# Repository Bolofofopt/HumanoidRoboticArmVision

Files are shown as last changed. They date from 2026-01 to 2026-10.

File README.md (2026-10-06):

<div align="center">

# 🤖 Vision-Controlled Robotic Arm

**A 3D-printed robotic arm that mimics your movements in real time using just a camera.**

<video src="media/demo.mp4" controls controlsList="nodownload"></video>







</div>

---

> **🌐 Language Note:** This README is written in **English**. However, the full technical report ([PDF](RIA_G7_Relatorio_Final_Braco_Robotico.pdf)) is in **Portuguese**. All source code files have two versions: an English version and a Portuguese version (files ending in `_PT`). Both versions are functionally identical; only comments and variable names differ. Use whichever you prefer.

---

## 📖 What Is This Project?

This is a **humanoid robotic arm** that imitates your arm and hand movements in real time. Instead of buttons or joysticks, you simply stand in front of a camera: the system recognizes your gestures and the robot copies them automatically.

The arm has **7 independent degrees of freedom**: 5 fingers that open and close, an elbow that goes up and down, and a rotating base that turns left and right. The entire mechanical structure was 3D-printed using the open-source [InMoov](https://inmoov.fr/) project as a foundation.

**This README is a complete tutorial.** If you follow every step, you'll be able to build your own robotic arm, even without much experience in programming or electronics.

---

## 🎬 Demo

https://github.com/user-attachments/assets/58556680-eb30-46fe-b466-be9ada0d2111

---

## 📁 Repository Structure

Before starting, it's useful to know where everything is:

```
HumanoidRoboticArmVision/
│
├── 📄 README.md                          ← You are here! The full tutorial
├── 📄 REQUIREMENTS.txt                   ← Software versions and libraries
├── 📄 LICENSE                            ← MIT License
├── 📄 RIA_G7_Relatorio_Final_Braco_Robotico.pdf  ← Full technical report (Portuguese)
│
├── 📂 code/
│   ├── 📂 Arduino/Final_Ard/
│   │   ├── 📂 MotorDriver/               ← Arduino MEGA firmware (English)
│   │   ├── 📂 MotorDriver_PT/            ← Arduino MEGA firmware (Portuguese)
│   │   └── 📂 Arduino_Uno_CNC_Final/     ← Arduino Uno firmware (stepper motor)
│   │
│   ├── 📂 RPi/Final_RPI/
│   │   ├── ArmController.py              ← Computer vision for Raspberry Pi (English)
│   │   └── ArmController_PT.py           ← Computer vision for Raspberry Pi (Portuguese)
│   │
│   └── 📂 PC/
│       ├── VisionDebugger_PC.py           ← Debug tool for PC (English)
│       ├── VisionDebugger_PC_PT.py        ← Debug tool for PC (Portuguese)
│       ├── hand_landmarker.task           ← MediaPipe model (hand)
│       └── pose_landmarker_lite.task      ← MediaPipe model (body)
│
├── 📂 Codigos_PDFs/                       ← Source code as PDF (report annexes, Portuguese)
│
└── 📂 media/                              ← Project images and GIFs
```

> **Note:** Each code file exists in **two versions**: English and Portuguese (`_PT` suffix). They are functionally identical; only the comments and variable names change.

---

## 🧾 Bill of Materials

Here's everything you need to build the arm. Some components can be swapped for equivalents.

### Electronics & Computing

| Component | Reference | Qty | Notes |
| :--- | :--- | :-: | :--- |
| Raspberry Pi | **Raspberry Pi 5** (8GB) |  1  | The "brain", processing real-time AI vision |
| Camera | **Raspberry Pi Camera Module 3** |  1  | Dedicated CSI camera for the RPi |
| Camera Cable (RPi 5) | **22-pin to 15-pin FPC cable** |  1  | Required adapter cable for RPi 5 mini-CSI port |
| MicroSD Card | **32 GB or 64 GB** (Class 10/A2) |  1  | OS (Bookworm) & software drive for Raspberry Pi 5 |
| Active Cooler | **Official RPi 5 Active Cooler** |  1  | Recommended heatsink + fan to avoid thermal throttle  |
| Arduino | **Arduino MEGA 2560** |  1  | Central motor controller |
| Arduino | **Arduino Uno R3** |  1  | Dedicated to the base stepper motor |
| Servo Driver | **PCA9685** (16-channel, I2C) |  1  | Controls all servos using just 2 pins |
| Stepper Driver | **A4988** |  1  | Plugs into the CNC Shield (with mini heatsink) |
| CNC Shield | **CNC Shield V3** |  1  | Mounts directly on the Arduino Uno |

### Motors & Actuators

| Component | Reference | Qty | Notes |
| :--- | :--- | :-: | :--- |
| Servo Motor (elbow) | **DS5160** (60 kgf·cm) |  1  | Needs to be powerful to support the forearm's weight  |
| Servo Motor (fingers + wrist) | **MG996R** (9-11 kgf·cm) |  6  | 5 for fingers + 1 for wrist rotation |
| Stepper Motor (base) | **17HS4401S** (NEMA 17) |  1  | Precise rotation of the base (Yaw axis) |

### Structure & Mechanics

| Component | Specification | Qty | Notes |
| :--- | :--- | :-----: | :--- |
| PLA Filament | 1.75mm, 1 kg spool |  ~1 kg  | For 3D printing all parts (hand, forearm, custom base, etc.) |
| Springs | 3/16″ x 1-3/4″ (4.8mm x 44.5mm) | 5 | Finger return mechanism |
| Tendons | Braided fishing line, 0.8mm, 200LB | 5x 50cm | Pull the fingers closed (~2.5m total) |
| Teflon Tubes | ID 1.5mm x OD 2.5mm | ~160cm  | Guide the tendons through forearm and fingers |
| Bearing | Commercial ball bearing | 1 | Connects fixed base to rotating upper base |
| Magnets | Neodymium Ø 2.5mm, height 1mm | 5 | Magnetic fingertip attachments |

### Power & Connectivity

| Component | Specification | Notes |
| :--- | :--- | :--- |
| Power Supply 1 | **7V / 3A DC** | For the servo motors (via PCA9685 V+ screw terminal) |
| Power Supply 2 | **12-13V / 2A DC** | For the stepper motor (via CNC Shield power screw) |
| RPi 5 Power | **Official 27W USB-C (5V/5A)** | Powers the Raspberry Pi 5 (and USB-connected boards) |
| USB Cables | **USB-A to USB-B** (2 units) | Connects both Arduinos to PC/RPi |
| DC Jack Adapters | **5.5×2.1mm to screw terminal**| 2 units to wire DC supplies into screw terminals |
| Dupont Jumper Wires | **M-F & M-M ribbon set (40p)** | UART serial (RPi ↔ MEGA ↔ Uno) and I2C connections |

### Consumables & Fasteners

| Component | Notes |
| :--- | :--- |
| Assorted screws (M3, M4) | M3 (8–30mm) & M4 screws, nuts, and washers for assembly |
| Heat shrink tubing | To insulate soldered wire joints |
| Hookup wire (Cabo unifilar) | Power distribution and common ground connections |
| Polyimide tape (Kapton) | Heat protection and wire bundling |
| Soldering flux & solder wire  | RMA flux and solder for secure electrical connections |
| Ecoflex™ 00-10 (RTV Silicone) | Optional: molded grip pads on fingertips |

---

## 💰 Estimated Project Cost

Below is an estimated cost breakdown for the entire project, based on **European market prices (October 2026)**. Prices are in **EUR (€)** and reflect typical online retail prices including VAT.

> **💡 Clones vs. Official:** Components marked with ★ have widely used compatible/clone alternatives (e.g., AliExpress, Amazon). Choosing clones for the microcontrollers and drivers can save **€50–€80** without sacrificing functionality.

### 1. Computing & Control Electronics

| Component | Ref. / Spec | Qty |  Unit Price  | Subtotal | Notes |
| :--- | :--- | :-: | :---: | :---: | :--- |
| Raspberry Pi | RPi 5 (8 GB) |  1  |  ~€85.00 ¹ | ~€85.00 | ¹ Official MSRP; street retail €90–€105 |
| Camera Module | RPi Camera Module 3 |  1  | ~€28.00 | ~€28.00 | Standard CSI camera (12 MP, autofocus) |
| Camera Adapter Cable | 22-pin mini to 15-pin FPC (RPi 5) |  1  | ~€3.50 | ~€3.50 | Required: RPi 5 uses mini CSI connector |
| MicroSD Card | 32 GB or 64 GB (Class 10 / A2) |  1  | ~€8.00 | ~€8.00 | For Raspberry Pi OS (Bookworm) & software  |
| Active Cooler | Official RPi 5 Active Cooler |  1  | ~€6.00 | ~€6.00 | Prevents thermal throttling during vision  |
| Arduino ★ | Arduino MEGA 2560 |  1  |  ~€20.00 ² | ~€20.00 | ² Quality clone; official Arduino is ~€45  |
| Arduino ★ | Arduino Uno R3 |  1  |  ~€12.00 ² | ~€12.00 | ² Quality clone; official Arduino is ~€28  |
| Servo Driver | PCA9685 (16-ch, I2C) |  1  | ~€5.00 | ~€5.00 | ★ Clones available from ~€3.50 |
| Stepper Driver | A4988 |  1  | ~€4.00 | ~€4.00 | Includes mini aluminum heatsink |
| CNC Shield | CNC Shield V3 |  1  | ~€5.00 | ~€5.00 | Plugs directly onto Arduino Uno |
| **Computing Subtotal**  | | | | **~€176.50** | |

### 2. Motors & Actuators

| Component | Ref. / Spec | Qty |  Unit Price  | Subtotal | Notes |
| :--- | :--- | :-: | :---: | :---: | :--- |
| Servo Motor (elbow) | DS5160 (60 kgf·cm) |  1  | ~€35.00 | ~€35.00 | High-torque digital metal-gear servo |
| Servo Motor (fingers + wrist) | MG996R (metal gear) |  6  |  ~€8.90 ³ | ~€53.40 | ³ Retail unit price; 6-pack clones ~€28  |
| Stepper Motor (base) | 17HS4401S (NEMA 17) |  1  | ~€12.00 | ~€12.00 | Standard bipolar stepper for base yaw |
| **Motors Subtotal** | | | | **~€100.40** | **~€75.00** with clone 6-pack |

### 3. Power & Connectivity

| Component | Specification | Qty |  Unit Price  | Subtotal | Notes |
| :--- | :--- | :-: | :---: | :---: | :--- |
| Power Supply 1 | 7 V / 3 A DC |  1  | ~€15.00 | ~€15.00 | Powers servos via PCA9685 V+ terminal |
| Power Supply 2 | 12 V / 2 A DC |  1  | ~€12.00 | ~€12.00 | Powers stepper via CNC Shield |
| RPi 5 Power Supply | Official 27 W USB-C (5V/5A) |  1  | ~€14.00 | ~€14.00 | Recommended official supply |
| USB Cables | USB-A to USB-B (for Arduinos)  |  2  | ~€4.00 | ~€8.00 | Connects Uno & MEGA |
| DC Jack Adapters | 5.5×2.1mm female to screw ter. |  2  | ~€1.00 | ~€2.00 | Wire barrel PSUs into screw terminals |
| Dupont Jumper Wires | 40-pin ribbon (M-M & M-F) |  1  | ~€3.50 | ~€3.50 | For UART & I2C communication wires |
| **Power Subtotal** | | | |  **~€54.50** | |

### 4. Structure, Hardware & Mechanics

| Component | Specification | Qty |  Unit Price  | Subtotal | Notes |
| :--- | :--- | :-: | :---: | :---: | :--- |
| PLA Filament | 1.75 mm, 1 kg spool |  1  | ~€20.00 | ~€20.00 | ~1 kg used for arm, base, and brim/test |
| Extension Springs | 3/16″ × 1-3/4″ (4.8mm × 44.5mm) |  5  | N/A | ~€7.50 ⁴  | ⁴ What we paid: €7.49 |
| Tendons (Fishing Line) | Braided 200 LB, 0.8 mm (100m spool) |  1  | N/A | ~€8.00 ⁴  | ⁴ What we paid: €8.12 |
| Teflon Tubes (PTFE) | ID 1.5 mm × OD 2.5 mm (~1.6m) |  1  | N/A | ~€2.00 ⁴  | ⁴ What we paid: €2.00 |
| Bearing | Deep groove ball bearing (base joint) |  1  | ~€3.00 | ~€3.00 | Commercial hardware for rotating base |
| Neodymium Magnets | Ø 2.5 mm × 1 mm |  5  | N/A | ~€4.60 ⁴  | ⁴ What we paid: €4.60 |
| Screws & Fasteners Kit | Assorted M3 / M4 (screws, nuts, etc.) |  1  | ~€10.00 | ~€10.00 | Hex socket screws, nuts, and washers |
| **Structure Subtotal** | | | |  **~€55.10** | |

### 5. Consumables & Assembly Supplies

| Component | Specification / Ref. |  Subtotal  | Notes |
| :--- | :--- | :---: | :--- |
| Heat shrink tubing | Assorted diameters | ~€3.50 ⁴ | ⁴ What we paid: €3.51 |
| Polyimide tape (Kapton) | Ref. 095-0793 | ~€5.00 ⁴ | ⁴ What we paid: €5.03 |
| Hookup wire (Cabo unifilar) | Single core copper wire  | ~€4.50 ⁴ | ⁴ What we paid: €4.49 |
| Soldering Flux & Solder | RMA Flux (Ref. 096-0207) | ~€5.00 ⁴ | ⁴ Flux €1.99 + solder wire for wire splices |
| Ecoflex™ 00-10 *(optional)* | RTV Silicone trial kit |  ~€35.00 ⁴ | ⁴ What we paid: €35.00 (fingertip pads) |
| **Consumables Subtotal** | | **~€18.00**| **~€53.00** including Ecoflex™ 00-10 |

### 📊 Total Estimated Cost Comparison

| Scenario | Estimated Total |
| :--- | :---: |
| 🟢 **Budget Build** (AliExpress clones, servo multipack, no Ecoflex) | **~€330 – €370** |
| 🟡 **Mid-range Build** (mix of official/quality clones, without Ecoflex) | **~€400 – €440** |
| 🟡 **Mid-range Build** (with Ecoflex silicone grip pads) | **~€435 – €475** |
| 🔴 **Full Official Build** (official Arduinos, retail prices, all accessories + Ecoflex) | **~€510 – €570** |

> **🎓 What We Actually Spent (Our Real Out-of-Pocket Cost):**
> When we built this arm at our university, we didn't have to buy everything from scratch. As you can see in our project report ([`RIA_G7_Relatorio_Final_Braco_Robotico.pdf`](RIA_G7_Relatorio_Final_Braco_Robotico.pdf), Section 5.5, Table 4), our lab already had key high-value components in stock (*"emStock"*): the **Raspberry Pi 5**, **Camera Module 3**, **Arduino MEGA**, **Arduino Uno**, **CNC Shield V3**, **DS5160 Servo**, and **NEMA 17 Stepper**.
>
> Because of that, our **actual out-of-pocket spending was only ~€73 to €118** (mainly for the springs, teflon tubes, fishing line, magnets, heat shrink, Kapton tape, wires, flux, and silicone). If you're building this in a university or makerspace with shared equipment, your upfront cost will likely be similarly low!

> **📝 Notes from Our Experience:**
> - **Raspberry Pi 5 Availability:** It's the most expensive component in the build. We recommend buying from official approved resellers (like Kubii, BerryBase, or Pimoroni) near MSRP (~€85–€90), as general marketplaces like Amazon often mark it up to €95–€110 depending on stock.
> - **3D Printing:** We printed all our parts on our Bambu Lab A1. If you don't have access to a 3D printer and need to outsource the printing, expect an additional commercial printing fee of €40–€90.
> - **Bulk Consumables:** We had to buy items like fishing line (100m spool), PTFE tubing, screws, and magnets in packs much larger than what our arm actually needed, so you'll end up with plenty of leftover materials for future maker projects, just like we did.

---

## 🔧 Step 1: 3D Printing the Parts

The arm's structure is based on the open-source **InMoov** project. You need to download the STL files and print them.

### Where to Download the Models

| Part | Link |
| :--- | :--- |
| 🖐️ Hand and Forearm  | [InMoov: Hand and Forearm](https://inmoov.fr/hand-and-forarm) |
| 🖐️ Hand (I2 version) | [InMoov: Hand I2](https://inmoov.fr/hand-i2) |
| 🏗️ Custom Base | [Custom Base STL Files](Custom_Base_STL/) |

> **💡 Note:** The base parts are not from InMoov. They were exclusively created by us for this project. You can find the STL files in the `Custom_Base_STL` folder in this repository.

> **💡 Tip:** The **Hand I2** version is the most recent and includes design improvements for the fingers. We recommend using this one.

### Print Settings

We used a **Bambu Lab A1** printer, but any FDM printer will work with these settings:

| Parameter |  InMoov Parts | Custom Parts (Base) |
| :--- | :---: | :---: |
| **Material** | PLA | PLA |
| **Nozzle Temperature** | 220°C | 220°C |
| **Bed Temperature** | 65°C | 65°C |
| **Layer Height** | 0.20mm | 0.20mm |
| **Infill Density** | **30%** | **25%** |
| **Wall Loops** | 2 | 2 |
| **Speed** | Standard (100%) | Standard (100%) |

### ⚠️ Common Issue: Warping

During printing, part edges may lift off the bed (called _warping_). If this happens:

1. **Enable "Brim"** in your slicer: this creates a thin rim around the part that increases bed adhesion.
2. **You don't need** to raise the bed temperature or lower the speed. With Brim enabled, standard settings work just fine.

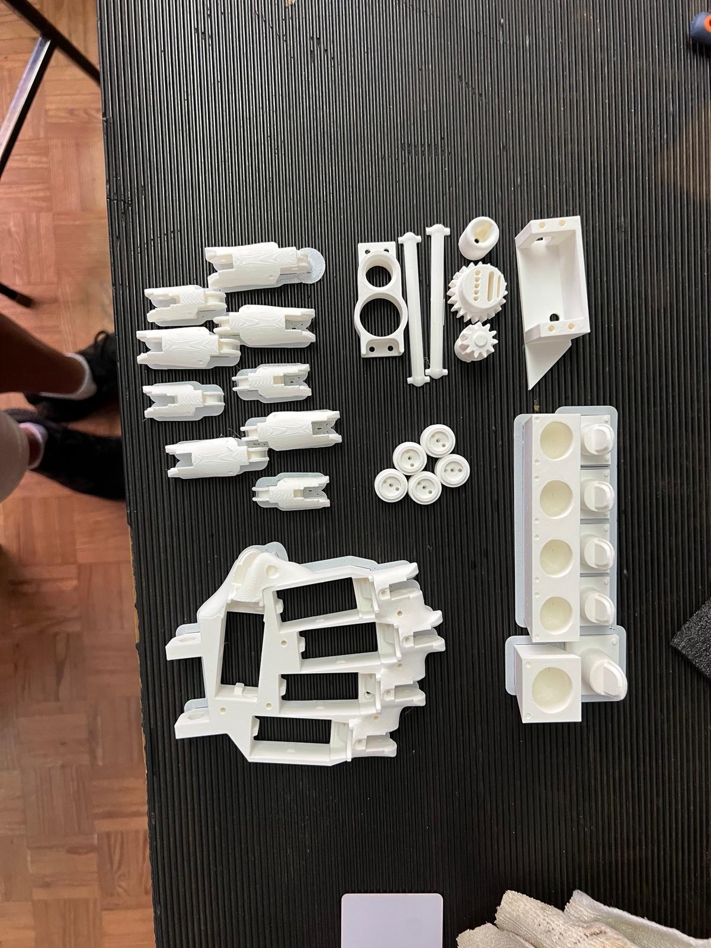
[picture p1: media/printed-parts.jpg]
3D printed parts


---

## 🔩 Step 2: Mechanical Assembly

After printing all the parts, it's time to assemble.

### Hand and Forearm Assembly

Follow the official InMoov instructions:

- 📘 [Assembly guide: Hand and Forearm](https://inmoov.fr/hand-and-forarm)
- 📘 [Assembly guide: Hand I2](https://inmoov.fr/hand-i2)

Each InMoov page has step-by-step photos and videos explaining how to thread the tendons (fishing line), install the return springs, and route the teflon tubes.

### Base Assembly (Custom Part)

The base **is not part of InMoov**; we designed it ourselves in SolidWorks for this project. It includes:

- **Main structure**: houses the stepper motor, Raspberry Pi, and both Arduinos.
- **Motor spacers**: ensure the motor shaft reaches the rotary coupling.
- **Arm coupling interface**: two pieces (lower base + upper base) that connect the bearing to the arm.
- **Rotary coupling**: transmits motion from the stepper motor to the rotating platform.
- **Motor mount bracket**: secures the motor to the main structure.

> **💡 Why a custom base?** The InMoov project includes a full torso, but we only needed the arm. So we designed a compact base that houses all the electronics and supports the arm's weight without overloading the motor.

| Assembly Process | Assembled Arm |
| :---: | :---: |
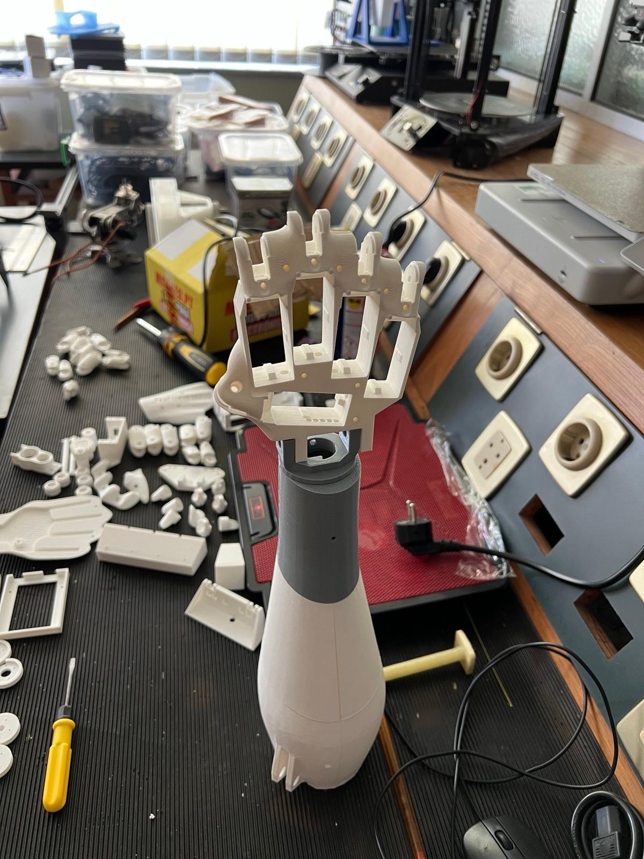
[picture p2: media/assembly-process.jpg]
Assembly process
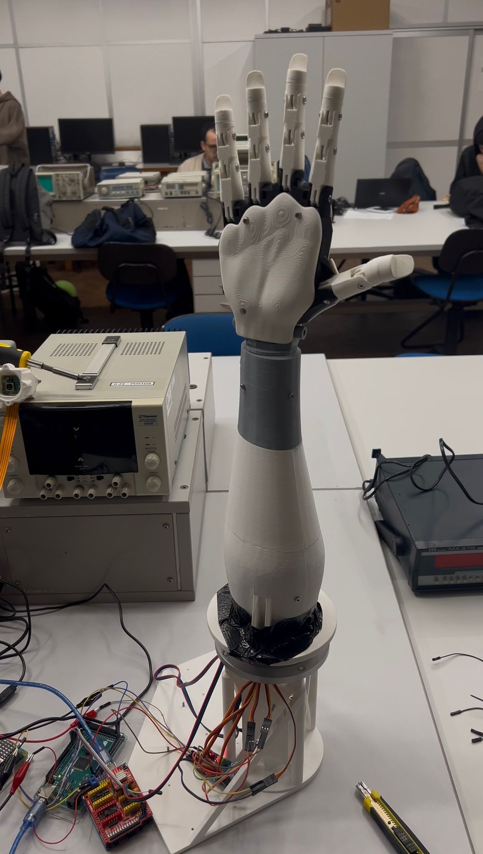
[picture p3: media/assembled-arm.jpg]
Assembled arm
|  |  |

---

## ⚡ Step 3: Electronics & Wiring

This is the part that requires the most attention. The system uses **three processors** working together:

```
┌──────────────┐     UART     ┌──────────────────┐     UART     ┌──────────────┐
│ Raspberry Pi │ ──────────►  │  Arduino MEGA    │ ──────────►  │  Arduino Uno │
│   5 (8GB)    │  GPIO14→RX1  │     2560         │  TX1→RX      │              │
│              │              │                  │              │ + CNC Shield │
│ Vision (AI)  │              │ Central Control  │              │ Stepper Motor│
└──────────────┘              └──────────────────┘              └──────────────┘
                                      │
                                      │ I2C (SDA/SCL)
                                      ▼
                              ┌──────────────────┐
                              │    PCA9685       │
                              │  Servo Driver    │
                              │  (16 channels)   │
                              └──────────────────┘
                                      │
                          ┌───────────┼───────────┐
                          ▼           ▼           ▼
                      MG996R Servos  DS5160 Servo  ...
                      (fingers/wrist) (elbow)
```

> **💡 Why three processors instead of one?** The Raspberry Pi needs all its processing power for the AI-based vision. If it also had to control motors at the same time, everything would lag and the movements would be jerky. By splitting the tasks, each processor does what it's best at, with no delays.

### Wiring Table

| From (Source)  | To (Destination) |  Type  | Source Pins |  Dest. Pins | What It Does |
| :--- | :--- | :----: | :---: | :---: | :--- |
| Raspberry Pi 5 | Arduino MEGA |  UART  | GPIO 14 (TX) | Pin 19 (RX1)  | Sends vision data |
| Arduino MEGA | Arduino Uno |  UART  | Pin 18 (TX1) |  Pin 0 (RX) | Sends base commands ('0','1','2') |
| Arduino MEGA | PCA9685 |  I2C | SDA (20) / SCL (21) | SDA / SCL | Controls the 7 servo motors |
| Arduino Uno | CNC Shield V3 | Shield | Pins 2, 5, 8 | STEP, DIR, EN | Controls the stepper motor |
| 7V/3A Supply | PCA9685 |  Wire  | N/A |  V+ terminal  | Powers the servo motors |
| 12V/2A Supply  | CNC Shield |  Wire  | N/A | 12V terminal  | Powers the stepper motor |

> **⚠️ IMPORTANT:** Connect the **GND** (ground) of all components together. Without a common ground, serial communication will not work.

### The PCA9685 Module: Simplified Servo Control

The PCA9685 is a key component. Without it, you'd need 7 PWM pins from the Arduino to control 7 servos, and the Arduino doesn't have that many stable PWM pins. With the PCA9685:

- You control **up to 16 servos** using just **2 pins** (I2C: SDA and SCL).
- The **motor power** comes from an external supply (7V), not from the Arduino. This protects the Arduino from current spikes.

### CNC Shield V3 + A4988: Stepper Motor

The CNC Shield plugs directly into the Arduino Uno and accepts the A4988 driver. The connections are automatic: just plug it in and wire the stepper motor to the X-axis terminals.

> **💡 Why separate power supplies?** Motors draw a lot of current and generate electrical noise. If they shared the same supply as the Arduinos, the Arduinos could randomly restart or behave erratically. Separate supplies = stable system.

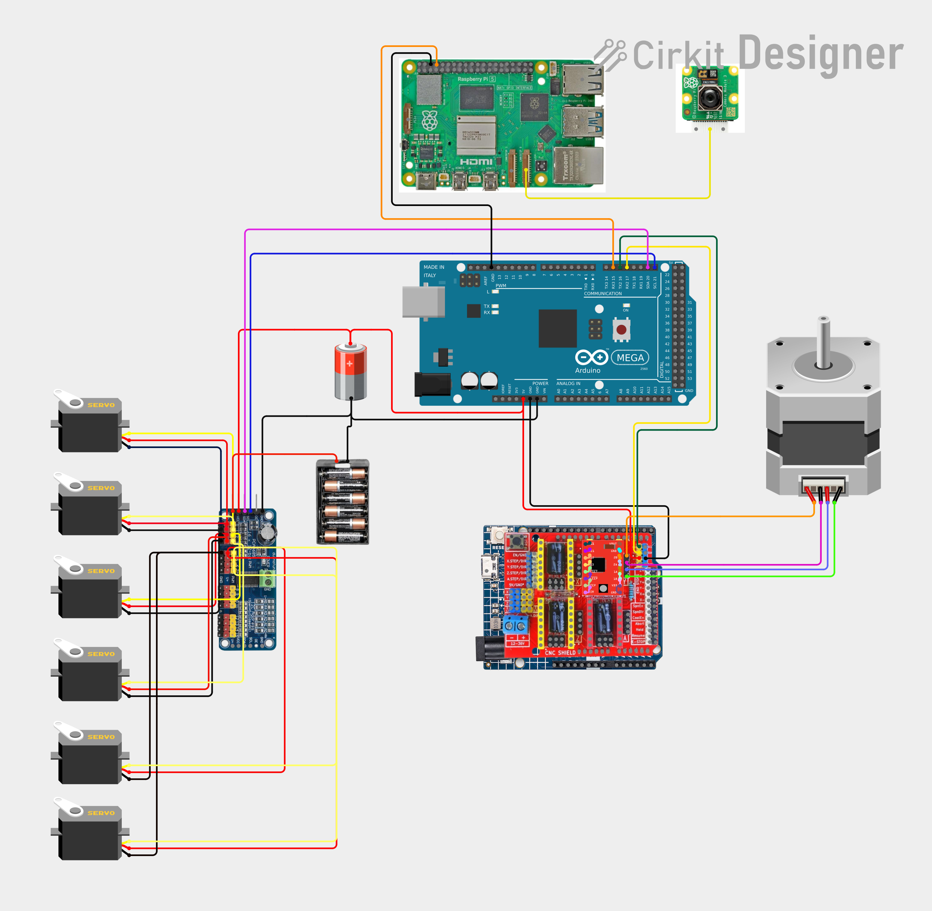
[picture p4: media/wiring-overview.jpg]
Wiring overview


For the full interactive wiring diagram, visit the [Cirkit Designer project](https://app.cirkitdesigner.com/project/).

---

## 💾 Step 4: Software (Arduino Firmware)

The firmware is the code that runs inside the Arduinos. You need to upload two different programs.

### 4.1: Arduino Uno (Base Stepper Motor)

**File:** [`Arduino_Uno_CNC_Final.ino`](code/Arduino/Final_Ard/Arduino_Uno_CNC_Final/Arduino_Uno_CNC_Final.ino)

**What it does:** Receives simple commands (`'0'`, `'1'`, or `'2'`) from the Arduino MEGA and rotates the stepper motor to the correct position (left, center, or right).

**How to upload:**

1. Open the **Arduino IDE**.
2. Connect the **Arduino Uno** to your PC via USB.
3. Go to _Tools > Board > Arduino Uno_.
4. Open the `Arduino_Uno_CNC_Final.ino` file.
5. Click **Upload** (→).

### 4.2: Arduino MEGA (Servo Control)

**File:** [`MotorDriver.ino`](code/Arduino/Final_Ard/MotorDriver/MotorDriver.ino) (English) or [`MotorDriver_PT.ino`](code/Arduino/Final_Ard/MotorDriver_PT/MotorDriver_PT.ino) (Portuguese)

**What it does:** Receives a data string from the Raspberry Pi (via UART), parses the values, and sends the correct PWM signals to each servo motor through the PCA9685.

**How to upload:**

1. **Install the required library:**
   - In Arduino IDE: _Sketch > Include Library > Manage Libraries_
   - Search for **"Adafruit PWM Servo Driver"** and install it.
2. Connect the **Arduino MEGA** to your PC via USB.
3. Go to _Tools > Board > Arduino Mega 2560_.
4. Open the `.ino` file and click **Upload** (→).

### How They Communicate

The two Arduinos talk to each other via **UART** (serial port). The MEGA acts as "Master" and the Uno as "Slave":

- The MEGA receives a complete data string from the Raspberry Pi.
- It extracts the base value and sends it to the Uno.
- The Uno interprets the command and moves the stepper motor.

---

## 🧠 Step 5: Software (Raspberry Pi Computer Vision)

This is the most exciting part: the brain of the system.

**File:** [`ArmController.py`](code/RPi/Final_RPI/ArmController.py) (English) or [`ArmController_PT.py`](code/RPi/Final_RPI/ArmController_PT.py) (Portuguese)

### 5.1: Install Dependencies

In the Raspberry Pi terminal, run:

```bash
pip install mediapipe opencv-python pyserial numpy --break-system-packages
```

> The `--break-system-packages` flag is required on Raspberry Pi OS Bookworm because it's very restrictive with pip packages by default.

### 5.2: Physical Connection (UART)

Connect the **GPIO 14 (TX)** on the Raspberry Pi to **Pin 19 (RX1)** on the Arduino MEGA with a wire. Also connect **GND** between the two.

> **⚠️ Voltage levels:** The Raspberry Pi operates at 3.3V and the Arduino at 5V. In practice, the Arduino reads 3.3V as HIGH without issues (RPi TX → Arduino RX). If you need to send data from the Arduino to the RPi, use a voltage divider.

### 5.3: Run

```bash
python3 ArmController.py
```

The system will:

1. Start the camera.
2. Detect your hand and shoulder using AI (MediaPipe).
3. Calculate angles and finger states.
4. Send the commands to the Arduino MEGA via UART.

### 5.4: Headless Mode (No Monitor)

The Raspberry Pi can run without a monitor. Use the [**Raspberry Pi Connect**](https://www.raspberrypi.com/software/connect/) service to access the screen remotely from any browser. We recommend using a **5G mobile hotspot** for better speed and lower latency.

---

## 🖥️ Step 6: Software (PC Debugging & Testing)

If you want to test the computer vision **without having the robot assembled**, you can use the PC script.

**File:** [`VisionDebugger_PC.py`](code/PC/VisionDebugger_PC.py) (English) or [`VisionDebugger_PC_PT.py`](code/PC/VisionDebugger_PC_PT.py) (Portuguese)

### 6.1: Install Dependencies (PC)

```bash
pip install opencv-python mediapipe numpy
```

### 6.2: Required Model Files

The PC script uses a different MediaPipe API that needs model files. These are already included in the [`code/PC/`](code/PC/) folder:

- `hand_landmarker.task`
- `pose_landmarker_lite.task`

**These files must be in the same folder as the Python script.**

### 6.3: Run

```bash
python VisionDebugger_PC.py
```

You'll see a window with your webcam feed and the detected points (hand and body) drawn on top. The calculated values (angles, finger states, etc.) appear as text on screen, making calibration and debugging easy.

> **💡 Recommendation:** Use this tool to understand how the vision works before setting everything up on the Raspberry Pi. It's much easier to experiment and debug on a PC.

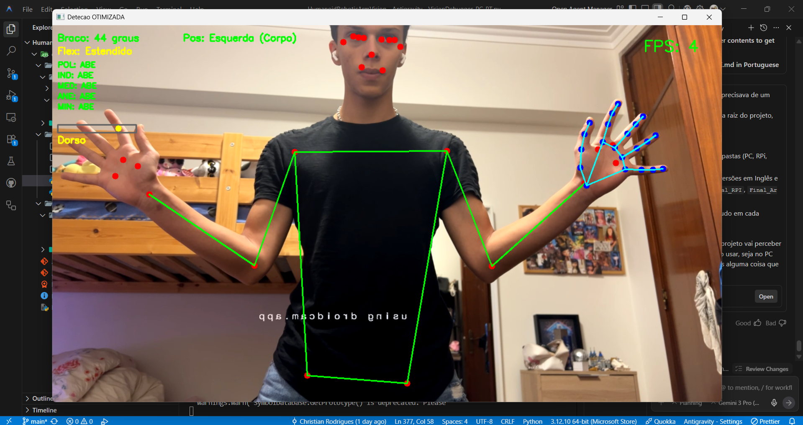
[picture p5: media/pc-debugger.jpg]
PC debugger interface


---

## 🧬 How the Vision Works (Simple Explanation)

The system uses Google's **MediaPipe** framework, which contains pre-trained AI models that detect 21 hand points and 33 body points in real time.

### How does it know if a finger is open or closed?

Instead of measuring the _distance_ between the fingertip and the wrist (which changes if you move closer to or further from the camera), the system calculates the **angle** at the finger's middle joint:

- **Large angle (> 160°)** → finger extended → **Open**
- **Small angle (< 160°)** → finger bent → **Closed**

> **💡 Why angles instead of distances?** Angles don't change with your distance from the camera. If you step back, the points get closer together on screen, but the angle at the joint stays the same. This makes the system much more reliable.

### How does it control the base (left/right)?

The system analyzes your **elbow angle** (using the shoulder, elbow, and wrist points):

- Arm folded (angle < 70°) → Base rotates **Left**
- Arm extended (angle > 130°) → Base rotates **Right**
- In between → Base stays at **Center**

### How does it control the elbow (up/down)?

It compares the **height of your wrist** to your shoulder:

- Wrist far below shoulder → Elbow stays **down**
- Wrist at shoulder level → Elbow goes **up**

### How does it control wrist rotation?

Since MediaPipe doesn't provide palm rotation directly, the system compares the relative position of the **thumb** and the **pinky finger**. Depending on your arm position (extended or bent), it automatically switches between using the X or Y axis to calculate rotation, and maps the result to 0°–180°.

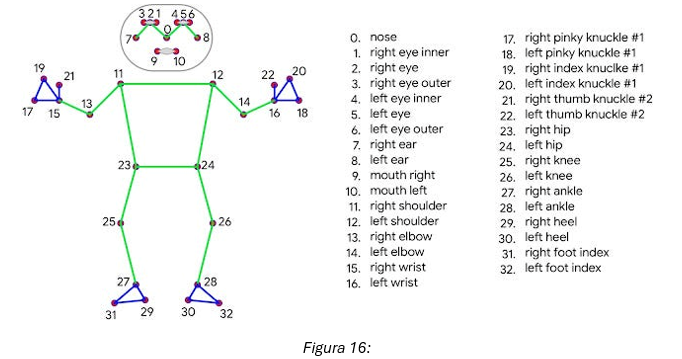
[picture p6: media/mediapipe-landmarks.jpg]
MediaPipe landmarks


---

## 📡 Communication Protocol

The Raspberry Pi sends a formatted string to the Arduino MEGA every video frame. The structure is:

```
$<Base>,<Elbow>,<D1>,<D2>,<D3>,<D4>,<D5>,<Rotation>\n
```

| Field | Values  | Meaning |
| :--- | :-----: | :--- |
| Base | 0, 1, 2 | Left, Center, Right |
| Elbow |  0, 1 | Extended, Bent |
| D1 to D5 |  0, 1 | State of each finger (0=open, 1=closed) |
| Rotation |  0–180  | Wrist rotation servo angle |

**Example:**

```
$1,0,1,1,1,1,1,90\n
```

> _Base at center, elbow extended, all fingers closed, wrist rotated to 90°._

The Arduino MEGA uses the `$` symbol to know where a message starts and `\n` to know where it ends. This ensures only complete messages are processed; if a message arrives cut off, it's simply ignored.

---

## 🔥 Common Problems & Solutions

| Problem | Likely Cause | Solution |
| :--- | :--- | :--- |
| Parts lifting off the print bed | Warping | Enable **Brim** in your slicer |
| Servos jitter or don't move | Insufficient power | Check that the 7V supply is connected to PCA9685 (**V+** terminal, not VCC) |
| Arduino resets on its own | Servos drawing current from Arduino | Use separate external power supplies; **never** power servos from the Arduino |
| Serial communication doesn't work | No shared ground | Connect **GND** of all devices together |
| `Serial port not found` on RPi | UART not enabled | Enable UART in `raspi-config` → _Interface Options > Serial Port_ |
| MediaPipe is slow on RPi | Heavy processing | Verify multithreading is active (CameraStream class in the code) |
| Hand not detected | Poor lighting | Improve ambient lighting; avoid backlight |

---

## 📊 Results

- **Frame rate:** 15–20 FPS on the Raspberry Pi 5, sufficient for real-time control.
- **Latency:** Noticeable but low, suitable for telepresence applications.
- **Finger accuracy:** The angle-based method is robust and works regardless of distance to the camera or hand rotation.
- **Stability:** The UART protocol didn't drop any packets during testing, ensuring smooth movements.

https://github.com/user-attachments/assets/0370e5d1-5927-4f3e-bb96-0c99ccfd8e14

### Current Limitations

- **Fingers** only have two states (open/closed), with no intermediate positions.
- **Shoulder** doesn't include the forward pitch movement, as it wasn't implemented.
- **Camera** is not fixed to the robot; it can misalign if the table is bumped.
- No **haptic feedback**: the operator can't feel what the robot touches.

---

## 💡 Ideas for Improvement

If you want to take the project further, here are some suggestions:

1. **Proportional finger control:** Instead of "open" or "closed", map your real finger angle directly to the servo angle. This way the robot copies the exact position.
2. **Integrated camera mount:** Design a part that attaches the camera to the robot's base, eliminating misalignment issues.
3. **More degrees of freedom:** Add the shoulder servo (Forward Pitch) so the arm can reach objects in front of it.
4. **Haptic feedback:** Install pressure sensors on the fingertips and vibration motors in a glove, so the operator "feels" what the robot touches.
5. **Professional base mounting:** Use clamps instead of adhesives to secure the robot to the workbench.

---

## 👥 Authors

| Name | Contact |
| :--- | :--- |
| **Henrique Abrantes** | [GitHub](https://github.com/Bolofofopt) |
| **Christian Rodrigues** | [GitHub](https://github.com/Crogued) |
| **Rodrigo Maria** | [GitHub](https://github.com/becas4wd) |

Project developed as part of the Robotics and Artificial Intelligence program at Escola Superior Náutica Infante D. Henrique (Portugal).

---

## 📚 References & Credits

- **InMoov** ([inmoov.fr](https://inmoov.fr/)): Gael Langevin's open-source project for the mechanical design of the hand and forearm.
- **MediaPipe** ([Google AI](https://ai.google.dev/edge/mediapipe/solutions/vision/hand_landmarker)): Computer vision framework for hand and pose detection.
- **OpenCV** ([opencv.org](https://opencv.org/)): Image processing library.
- **Raspberry Pi** ([raspberrypi.com](https://www.raspberrypi.com/documentation/computers/raspberry-pi.html)): Raspberry Pi 5 documentation.
- **Arduino** ([docs.arduino.cc](https://docs.arduino.cc/hardware/mega-2560)): Arduino MEGA 2560 documentation.
- **Cirkit Designer** ([Interactive wiring diagram](https://app.cirkitdesigner.com/project/)): Full schematic.

> For the complete technical analysis (torque calculations, mathematical foundations, detailed engineering decisions), see the [full report in PDF](RIA_G7_Relatorio_Final_Braco_Robotico.pdf) included in this repository (Portuguese).

> **AI Assistance Disclosure:** We used Claude and Gemini models as assistive tools during this project, helping us with software development, code refinement, and the writing and structuring of this README documentation. All mechanical engineering, hardware integration, and experimental testing were conducted by the authors.

---

## 📄 License

This project is licensed under the [MIT License](LICENSE); you are free to use, modify, and distribute it.

---

<div align="center">

**Made with ❤️, PLA, and a lot of patience.**

⭐ If this project helped you, leave a star on the repository!

</div>

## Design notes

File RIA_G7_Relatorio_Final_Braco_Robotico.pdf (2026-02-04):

## Projeto Integrado

### Professor Camilo Christo

## Braço Robótico com 2 graus de liberdade e mão robótica com 5 graus de liberdade

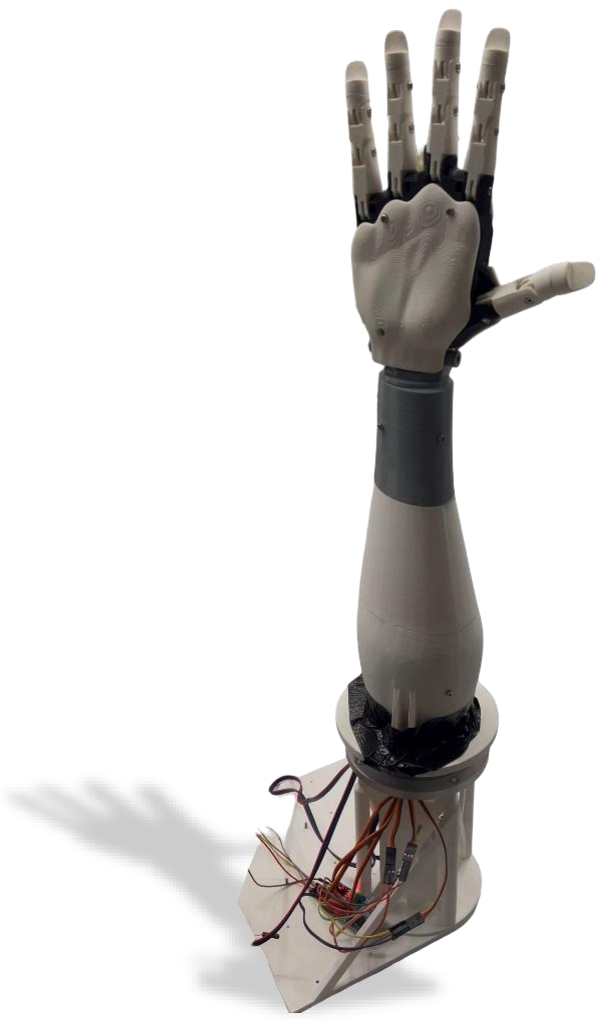
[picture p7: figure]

Feito por
Henrique Abrantes (15196@enautica.pt) Christian Rodrigues (15202@enautica.pt) Rodrigo Maria (15217@enautica.pt)

TeSP Robótica e Inteligência Artificial

Projeto Integrado — Braço Robótico Alunos: [15196, 15202, 15217] — Página 2 de 40

# Índice

5.1 | Resultados da Construção | 32
5.2 | Validação da Visão Computacional | 33
5.3 | Validação Funcional (Mimetização) | 35
5.4 | Desvios ao Projeto Inicial | 36
5.5 | Lista de Material Final | 37
6 | Conclusões e Trabalho Futuro | 37
6.1 | Propostas de Trabalho Futuro | 38
7 | Referências | 39

# Índice de Figuras

FIGURA 1: IMPRESSORA BAMBU LAB A1 DURANTE O PROCESSO DE IMPRESSÃO | 5
FIGURA 2: MODELO CAD DA BASE DO BRAÇO (MONTAGEM EM SOLIDWORKS) | 6
FIGURA 3 | FIGURA 4 | FIGURA 5 | 7
FIGURA 6 | | FIGURA 7 | 8
FIGURA 8 | FIGURA 9 | 8
FIGURA 10 | 8
FIGURA 11: DIAGRAMA DE BLOCOS | 13
FIGURA 12: DIAGRAMA DE LIGAÇÕES ELÉTRICAS E FLUXO DE SINAIS (GERADO EM CIRKIT DESIGNER).
VERSÃO INTERATIVA DISPONÍVEL EM [14] | 14
FIGURA 13: FLUXOGRAMA | 23
FIGURA 14: TOPOLOGIA DOS 21 LANDMARKS DETETADOS PELO MODELO MEDIAPIPE HANDS | 24
FIGURA 15: MAPEAMENTO DOS LANDMARKS CORPORAIS DO MODELO MEDIAPIPE POSE | 25
FIGURA 16: VISUALIZAÇÃO EM TEMPO REAL DAS LANDMARKS DETETADAS | 25
FIGURA 17: INTERFACE DE DEPURAÇÃO EM FUNCIONAMENTO | 26
FIGURA 18: CONJUNTO DE COMPONENTES ESTRUTURAIS DO BRAÇO PRODUZIDOS EM PLA | 32
FIGURA 19: VISTA GERAL DO SISTEMA ROBÓTICO PARCIALMENTE MONTADO | 32
FIGURA 20: COMPONENTE DA BASE SUPERIOR DO BRAÇO SUJEITO A ALTERAÇÕES PÓS-IMPRESSÃO | 33
FIGURA 21: DEMONSTRAÇÃO FUNCIONAL DO SISTEMA INTEGRADO | 34
FIGURA 22: SEQUÊNCIA DE TESTE FUNCIONAL EM TEMPO REAL | 36
FIGURA 23: MECANISMO DE ACOPLAMENTO DA BASE SUPERIOR | 36

# Índice de Tabelas

TABELA 1: CONFIGURAÇÕES DA IMPRESSORA | 6
TABELA 2: MOTORES UTILIZADOS | 11
TABELA 3: MAPEAMENTO DE PINOS E PROTOCOLOS DE COMUNICAÇÃO | 15
TABELA 4: LISTA DE MATERIAL | 37

# 1 Introdução

O presente projeto surge no âmbito da Unidade Curricular de Projeto Integrado, na qual foram propostos diversos temas para desenvolvimento. Após a análise das propostas iniciais, optou-se pela implementação de um projeto alternativo [1], focado no desenvolvimento de um braço robótico humanoide controlado por sistemas de visão computacional.

O objetivo central do trabalho consiste na conceção e assemblagem de um braço robótico com 2 graus de liberdade (DoF), permitindo a rotação da base (Yaw) e a elevação do cotovelo (Pitch). A este braço foi acoplada uma mão robótica antropomórfica com 5 dedos independentes, conferindo mais 5 DoF ao sistema (totalizando 7 DoF no conjunto).

A estratégia de controlo baseia-se no processamento de imagem em tempo real, onde o sistema interpreta os movimentos humanos e os replica nos servomotores. Relativamente à construção mecânica, toda a estrutura estrutural foi produzida integralmente através de processos de manufatura aditiva (impressão 3D), recorrendo aos equipamentos e recursos disponibilizados pela instituição de ensino.

# 2 Descrição do Projeto

O desenvolvimento deste sistema robótico antropomórfico resulta da integração multidisciplinar entre engenharia mecânica, eletrónica de potência e desenvolvimento de software. O presente capítulo detalha as etapas construtivas e as decisões de projeto que permitiram transformar o modelo teórico num protótipo funcional, capaz de mimetizar os movimentos do membro superior humano.

A descrição técnica encontra-se estruturada de forma sequencial, abordando as três camadas fundamentais do sistema:

1. Estrutura Mecânica: Descrição dos processos de manufatura aditiva (Impressão 3D), escolha de materiais e assemblagem das articulações baseadas no projeto open-source InMoov.
2. Hardware e Eletrónica: Análise da arquitetura de circuitos, distribuição de energia e seleção de atuadores (servomotores e motores de passo) e controladores (Arduinos).
3. Lógica de Controlo: Explicação dos algoritmos de firmware responsáveis pela gestão cinemática e comunicação entre os diversos módulos do sistema.

Ao longo das secções seguintes, são justificados os componentes selecionados e descritas as adaptações realizadas para cumprir os requisitos de estabilidade, torque e tempo de resposta do robô.

## 2.1 Manufatura Aditiva

Os modelos tridimensionais dos componentes estruturais do braço robótico tiveram como base um projeto já existente [2], devidamente citado nas referências.

Para o processo de fabrico via manufatura aditiva (Impressão 3D), recorreu-se aos recursos laboratoriais disponibilizados pela instituição de ensino. O equipamento selecionado para a produção integral das peças foi a impressora 'Bambu Lab A1'. Esta escolha justificou-se pela sua superior velocidade de deposição e elevada precisão dimensional em comparação com as restantes alternativas disponíveis no laboratório.

Relativamente à matéria-prima, optou-se pela utilização de filamento PLA (Ácido Polilático), devido às suas características mecânicas adequadas e facilidade de impressão.

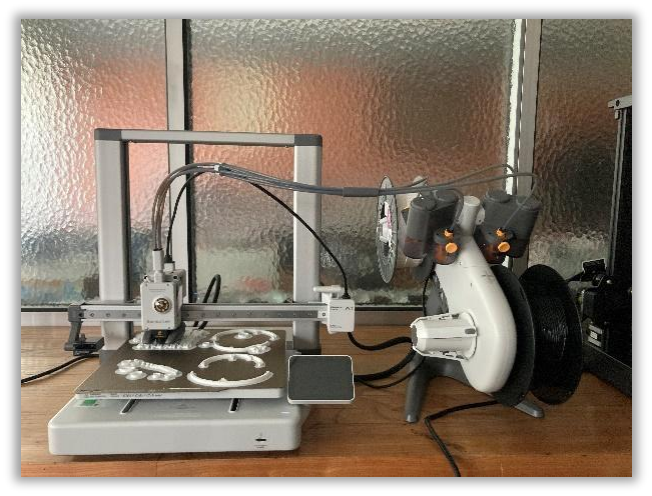
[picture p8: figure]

Figura 1: Impressora Bambu Lab A1 durante o processo de impressão.

Durante a fase inicial de fabrico, identificou-se um desafio técnico: após a deposição das primeiras camadas, observou-se o levantamento de uma das extremidades da peça, fenómeno tecnicamente designado por warping. Em consequência desta anomalia, foi necessário interromper o processo de impressão.

Numa primeira tentativa de mitigação, procedeu-se à elevação da temperatura da base aquecida (bed) de 65 ºC para 70 ºC, com o intuito de potenciar a aderência do material. Simultaneamente, reduziu-se a velocidade de impressão para o modo 'Silent' (50%). Contudo, estas medidas não se revelaram eficazes, persistindo o problema de descolamento.

Como solução definitiva, recorreu-se à implementação da técnica de 'Brim' (aba), que consiste na geração de uma estrutura periférica adicional em torno da peça. Esta técnica permitiu ampliar a área de contacto com a superfície de impressão, maximizando a aderência. Nesta configuração final, manteve-se a velocidade no modo 'Standard' (100%) e a temperatura da base nos 65 ºC, obtendo-se resultados satisfatórios.

As principais configurações da impressora para a impressão foram as seguintes:

Definições de impressão
Temperatura do extursor | 220º.C
Temperatura da mesa | 65º.C
Velocidade de Impressão | “Standart” 100%
“Wall Loops” por peça | 2
Tamanho da camada | 0.20mm
Densidade do “Infill” | 30%

Tabela 1: Configurações da impressora

## 2.2 Base do Braço e Estrutura

De forma a garantir a estabilidade mecânica do sistema e fornecer um grau de liberdade adicional (Yaw) ao conjunto, foi desenvolvido um suporte estrutural personalizado. Ao contrário da configuração padrão do projeto InMoov, que contempla um torso completo, este projeto exigiu a conceção de uma base compacta capaz de alojar os microcontroladores e suportar as cargas axiais e radiais exercidas pelo movimento do braço.

O design mecânico foi modelado em ambiente CAD (SolidWorks), priorizando a modularidade e a facilidade de montagem através de conexões parafusadas, conforme ilustrado na Figura 4.

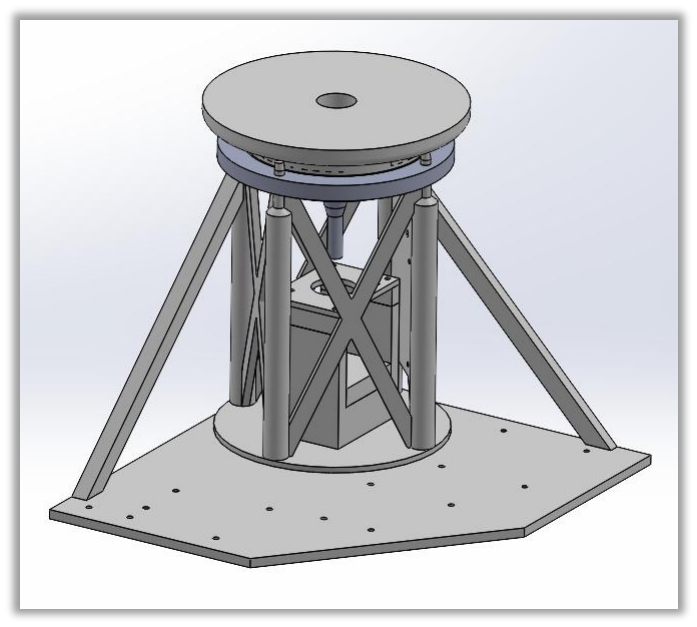
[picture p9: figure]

Figura 2: Modelo CAD da base do braço (montagem em Solidworks).

### 2.2.1 Componentes da Base:

- Estrutura principal da base (Fig. 5): Componente estrutural que aloja o Motor de passo, o Raspberry Pi, o Arduino MEGA e o Arduino Uno. Desempenha ainda a função crítica de suportar a carga axial (peso) do braço robótico, isolando o veio do motor de passo desse esforço mecânico.
- Espaçadores do Motor de passo (Fig. 6 e 7): Peças de extensão desenhadas para garantir o alinhamento vertical correto, permitindo que o veio do motor alcance o Acoplamento Rotativo (Fig. 10).
- Interface de Acoplamento do Braço (Fig. 8): Devido à área de contacto reduzida do rolamento (Fig. 12), foi necessário desenvolver uma interface intermédia. Esta estrutura é composta por dois segmentos: a Base do Braço Inferior (Fig. 8) e a Base do Braço Superior (Fig. 9). A base inferior acopla-se diretamente ao rolamento, enquanto a base superior se fixa à inferior, garantindo uma superfície estável para o braço.
- Acoplamento Rotativo (Fig. 10): Elemento de transmissão mecânica responsável pela união solidária entre o rolamento e o veio do motor de passo.
- Suporte de Fixação do Motor (Fig. 11): Componente que assegura a fixação rígida do motor à estrutura principal da base.
- Rolamento (Fig. 12): Elemento de ligação mecânica que conecta a estrutura estática da base à parte móvel (Base do braço inferior). Trata-se de um componente comercial (hardware não impresso).

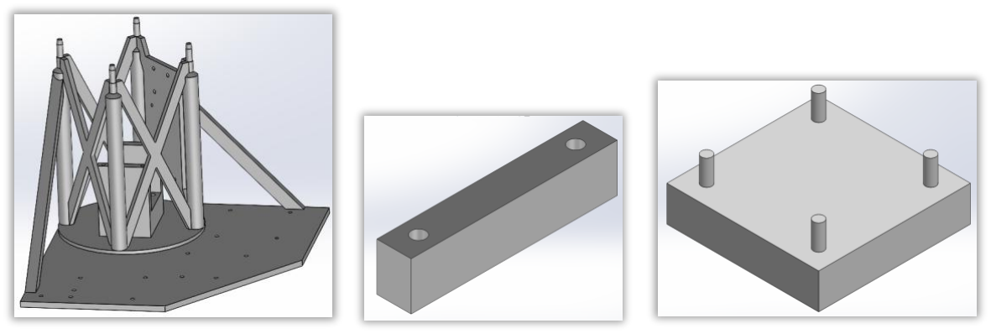
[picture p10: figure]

Figura 3 | Figura 4 | Figura 5

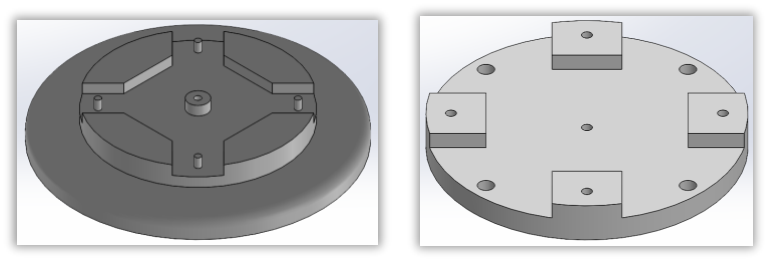
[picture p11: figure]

Figura 6 | Figura 7

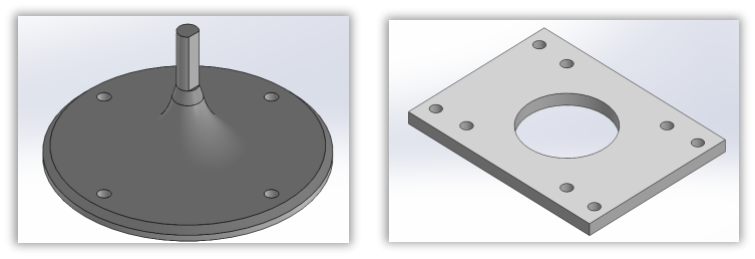
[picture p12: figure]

Figura 8 | Figura 9

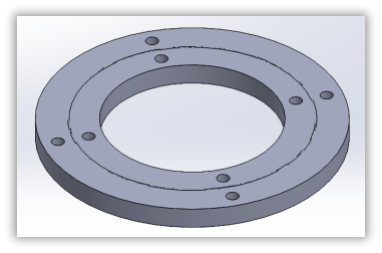
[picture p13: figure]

Figura 10

## 2.3 Atuadores e Cinemática

O processo de seleção dos servomotores baseou-se no cálculo do binário (torque) necessário para realizar os movimentos críticos do braço, garantindo a capacidade de suporte de carga e a estabilidade do sistema.

### 2.3.1 Motor do Cotovelo (Pitch)

Para esta articulação, o cálculo focou-se no binário estático necessário para vencer a força gravítica e sustentar o peso do antebraço e da mão. A equação fundamental do binário é dada por:

τ = F · l

Onde:

- τ: Binário (N · m)
- F: Força Peso (N), calculada por F = m · g
- l: Comprimento do braço de alavanca (distância ao ponto de rotação)

Considerando os seguintes parâmetros do projeto:

- Comprimento do braço de alavanca (l): 0.25m (25cm)
- Massa estimada do conjunto (m): ~ 1 Kg
- Aceleração gravítica (g): 9.80665m/s

2

Obtém-se o binário nominal:

Fbase = m · g

Combinando as fórmulas, temos:

τ = m · g · l

Substituindo a fórmula:

τbase = mgl → 1 ∗ 9.80665 ∗ 0.25 = 2.45N · m

Para garantir a robustez do sistema face a acelerações dinâmicas, vibrações e peso de cablagens não contabilizado, aplicou-se um Fator de Segurança (FS) de 1.1.

τfinal = 2.45 ∗ 1.1 = 2.7N · m

Convertendo | para | a | unidade | comercial | de | servomotores | (
1 N · m ~ 10.197 kgf · cm), o requisito mínimo é de aproximadamente 27.5 kgf · cm

Seleção: A escolha recaiu sobre o modelo DS5160, um servo digital com capacidade de

### 60 kgf · cm. Embora sobredimensionado face ao valor calculado, esta opção foi ditada

pela disponibilidade de stock na instituição, oferecendo em contrapartida uma excelente margem de segurança e estabilidade térmica.

### 2.3.2 Atuadores do Efeito Final (Dedos)

Para dimensionar os motores da mão, considerou-se a força de atrito necessária para a preensão segura de um objeto de massa conhecida (ex: bola de ténis), tendo em conta as propriedades do material dos dedos (PLA).

Parâmetros de Cálculo:

- Número de dedos (n): 5
- Massa do objeto (m): 0,06 kg
- Coeficiente de atrito estático (μ): 0,2 (caso desfavorável) a 0,5 (caso favorável)
- Comprimento do braço de momento (Ltotal): ≈ 0,18 m
- Fator de Segurança (FS): 2

Cálculo das Forças:

O peso do objeto (W) é calculado como:

W = m ⋅ g = 0.06 ⋅ 9.80665 = 0.59N

Força normal necessária em cada dedo (sem fator de segurança):

Ncada =

W
μ ⋅ n

Para μ = 0.2:

Ncada =

0.59
0.2 ⋅ 5

= 0.59N

Aplicando o fator de segurança:

Nreq = SF ⋅ Ncada = 2 ⋅ 0.59 = 1.18N

Binário necessário no atuador (caso desfavorável, μ = 0.2):

τmotor = Nreq ⋅ Ltotal = 1.18 ⋅ 0.18 = 0.22N · m (~2.24kgf · cm)

Caso favorável (μ = 0.5):

Ncada =

0.59
0.5 ⋅ 5

= 0.24N · m

Nreq = 2 ⋅ 0.24 = 0.47N · m
τmotor = 0.47 ⋅ 0.18 = 0.085N · m (~0.87kgf · cm)

Análise Crítica e Seleção:

Embora o cálculo teórico aponte para um requisito máximo de 2,24 kgf.cm, este modelo idealizado não contempla perdas mecânicas significativas do sistema real, tais como:

1. Atrito nos tendões e nas articulações impressas em 3D;
2. Elasticidade e deformação do material (PLA);
3. Distribuição desigual de carga entre os dedos;
4. Resistência mecânica oferecida pelas molas de retorno.

Estima-se que estas ineficiências possam elevar o requisito real de binário entre 5 e 10 vezes o valor teórico. Consequentemente, optou-se pela utilização de servomotores MG996R de engrenagens metálicas, com binário entre 9 e 11 kgf.cm. Esta escolha garante a força necessária para uma preensão firme, compensando todas as perdas por atrito e ineficiências mecânicas do sistema de cabos.

Para a base utilizou-se um motor de passo pela sua precisão.

Motores utilizados:

REFERÊNCIA | FORÇA | QUANTIDADE | UTILIDADE
SERVO DS5160 | 60kgf/cm | 1 | Cotovelo
SERVO MG996R | 9-11kgf/cm | 6 | Dedos e Pulso
STEP-MOTOR 17HS4401S | 4.3kgf/cm | 1 | Base

Tabela 2: Motores utilizados

## 2.4 Arquitetura de Hardware e Eletrónica

A arquitetura do sistema foi estruturada com base numa abordagem distribuída, compreendendo três unidades de processamento distintas: um Raspberry Pi 5 (RPi), responsável pelas tarefas de visão computacional de alto nível; um Arduino MEGA 2560, encarregue do controlo lógico de baixo nível e coordenação geral; e um Arduino Uno, dedicado exclusivamente ao acionamento e controlo do motor de passo da base.

- Raspberry Pi 5 (Visão Computacional) O Raspberry Pi 5 consiste num Single Board Computer (SBC) de elevado desempenho, operando sob o sistema operativo Linux. Distingue-se dos microcontroladores convencionais pela integração de um processador Quad-core Arm Cortex-A76 e memória RAM dedicada.

- Função no Projeto: Este dispositivo é responsável pela aquisição e processamento de vídeo em tempo real. A sua seleção deveu-se à capacidade de processamento necessária para executar tarefas computacionalmente exigentes, inviáveis para um microcontrolador padrão, tais como a execução de algoritmos de Inteligência Artificial e o cálculo da cinemática do braço. O software de visão foi implementado através de scripts na linguagem Python.
- Arduino MEGA 2560 (Controlo Central) O Arduino MEGA é uma placa de desenvolvimento baseada no microcontrolador ATmega2560, atuando neste sistema como a unidade central de coordenação e controlo.
- Função no Projeto: A opção pelo modelo MEGA, em detrimento do Uno para esta função específica, justifica-se pela disponibilidade de quatro portas de comunicação série por hardware (UART - Serial1, Serial2, etc.). Esta característica permite estabelecer comunicação de alta velocidade com o Raspberry Pi numa porta dedicada e, simultaneamente, transmitir comandos para o Arduino Uno numa segunda porta, evitando o uso de emulação por software (SoftwareSerial) e a consequente latência. Programado em C/C++, este módulo recebe os comandos angulares do RPi e gera os sinais de controlo precisos para os servomotores.
- Arduino Uno (Controlo do Motor de Passo) Esta unidade foi alocada exclusivamente ao controlo do motor de passo da base. Programado em C/C++, o Arduino Uno recebe as instruções de posicionamento provenientes do Arduino MEGA e converte-as nos sinais elétricos necessários para o acionamento preciso do motor.

### 2.4.1 Diagrama de Blocos do Hardware

Mostra como os cabos ligam as placas.

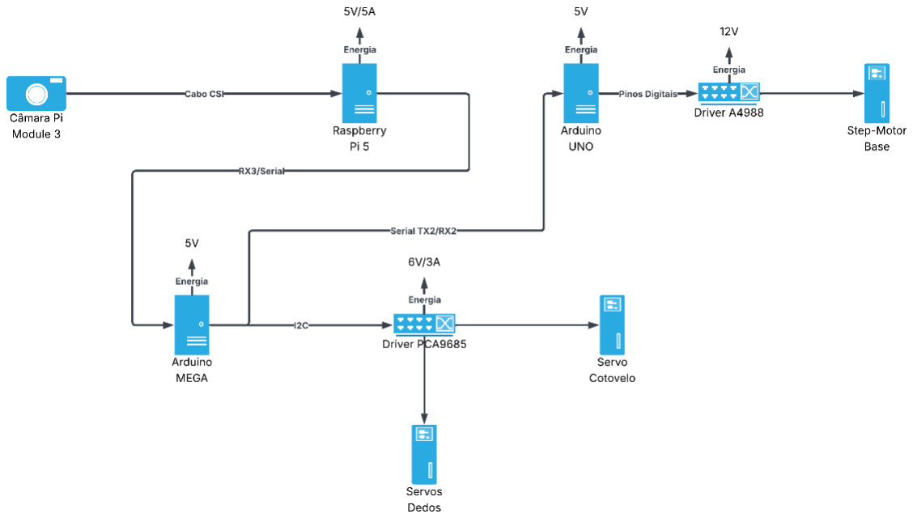
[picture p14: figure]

Figura 11: Diagrama de Blocos

### 2.4.2 Eletrónica e Alimentação

Devido ao elevado consumo energético dos atuadores mecânicos, optou-se pela utilização de duas fontes de alimentação de bancada independentes para isolar os circuitos de potência: uma fonte configurada a 7V/3A dedicada aos servomotores e uma segunda fonte a 13V/2A exclusiva para o motor de passo.

Relativamente aos microcontroladores, a alimentação do Arduino MEGA e do Arduino Uno é assegurada através da conexão USB. Por sua vez, o Raspberry Pi 5 recebe energia através de uma fonte de alimentação dedicada (transformador) ou baterias oficiais, garantindo a estabilidade de corrente necessária para o processamento.

- Servomotores (MG996R e DS5160): O conjunto de 7 servomotores (responsáveis pela actuação dos 5 dedos, do pulso e do cotovelo) recebe os sinais de controlo e a alimentação de potência através do módulo driver PWM (PCA9685), cujo funcionamento será detalhado na secção seguinte.
- Motor de Passo (17HS4401S): O controlo da base é efetuado por intermédio de um driver A4988. Este componente interpreta os sinais lógicos de STEP (passo) e DIR (direção) enviados pelo Arduino, sendo a alimentação de potência (13V, 2A) fornecida pela fonte externa mencionada anteriormente.

2.4.2.1 Eletrónica de Controlo (PCA9685)

Um desafio comum em projetos de robótica é o facto de o microcontrolador (Arduino) não possuir pinos PWM em número suficiente ou com corrente estável para controlar múltiplos motores em simultâneo. Por esse motivo, implementámos o controlador PCA9685. Este módulo permite controlar até 16 servomotores utilizando apenas dois pinos do Arduino (barramento I2C). Além disso, permite ligar uma fonte de alimentação externa dedicada aos motores, o que evita que o Arduino sofra quedas de tensão ou danos por picos de consumo de corrente

## 2.5 Esquema Elétrico e Interconexões

A integridade do sistema robótico depende de uma arquitetura elétrica robusta, capaz de interligar componentes com diferentes níveis de tensão lógica (3.3V no Raspberry Pi e 5V nos Arduinos) e isolar os circuitos de alta corrente (motores) dos circuitos de processamento.

A Figura 12 ilustra o diagrama esquemático completo desenvolvido na plataforma Cirkit Designer. Para uma análise detalhada de cada conexão e pinout, recomenda-se a consulta do diagrama digital interativo disponível nas referências [14].

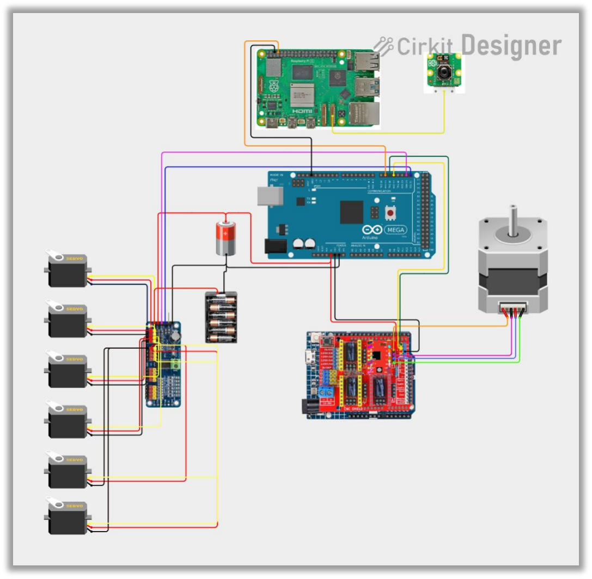
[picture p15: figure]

Figura 12: Diagrama de ligações elétricas e fluxo de sinais (Gerado em Cirkit Designer). Versão interativa disponível em [14].

### 2.5.1 Matriz de Interconexões

Para facilitar a leitura técnica e a replicação do projeto, a Tabela 3 resume as interfaces físicas estabelecidas entre os principais módulos do sistema.

ORIGEM
(MESTRE
/SINAL)

DESTINO
(ESCRAVO/R
ECEPTOR)

TIPO DE
CONEXÃO

PINOS
ORIGEM

PINOS
DESTI
NO

DESCRIÇÃ
O DA
FUNÇÃO

RASPBERRY
PI 5

Arduino
MEGA

UART
(Série)

GPIO 14
(TX)

Pin 19
(RX1)

Envio de
coordenada
s de visão
(Mão/Corp
o).

ARDUINO
MEGA
Arduino Uno | UART (Série) | Pin 18 (TX1) | Pin 0 (RX)

Envio de
comandos
p/ base ('0',
'1', '2').

ARDUINO
MEGA
Driver PCA9685 | I2C | SDA (20) / SCL (21) | SDA / SCL

Controlo
PWM dos 6
Servomotor
es.

ARDUINO
UNO
CNC Shield V3 | Shield (Direto) | Pinos 2, 5,
| | 8 | X-Step, X-Dir, En

Controlo do
Motor de
Passo
NEMA 17.

FONTE 1
(LOGIC)
Arduinos / RPi | USB / 5V | - | VCC / 5V

Alimentaçã
o dos
microcontro
ladores.

FONTE 2
(POWER)
Atuadores | Cabo AWG | - | Termin ais Ext.

Alimentaçã
o de carga
(Servos e
NEMA 17).

Tabela 3: Mapeamento de Pinos e Protocolos de Comunicação.

### 2.5.2 Gestão de Energia e Isolamento

Um dos pontos críticos do projeto foi a separação dos barramentos de alimentação para evitar que o ruído elétrico dos motores interferisse no processamento lógico ou causasse brownouts (quedas de tensão) nos Arduinos.

A. Driver de Servos (PCA9685):

O módulo PCA9685 possui dois terminais de alimentação distintos, configurados da seguinte forma:

- VCC (Lógica): Alimentado com 5V provenientes do Arduino MEGA. Este pino alimenta apenas o chip controlador do driver e a comunicação I2C.
- V+ (Potência): Conectado diretamente a uma fonte externa de 6V de alta amperagem. Esta entrada fornece a corrente exclusiva para o movimento dos servomotores, garantindo que o Arduino não suporta a carga elétrica dos atuadores.
B. CNC Shield V3 (Motor de Passo):

O shield acoplado ao Arduino Uno recebe uma alimentação externa de 12V nos bornes de potência, necessária para garantir o binário do motor NEMA 17. A lógica de controlo (STEP, DIR, ENABLE) opera a 5V, partilhando apenas o referencial de massa (Common Ground) com o restante sistema.

3 2.5.3. Configuração do Arduino Uno (Controlador da Base)

O Arduino Uno atua como um escravo dedicado, executando um firmware específico para a gestão do driver A4988. Conforme o código implementado, as ligações físicas no CNC Shield correspondem às definições padrão do Eixo X:

- Pino 2 (STEP): Recebe os pulsos de passo (onda quadrada) gerados pela função moveMotor().
- Pino 5 (DIR): Define o sentido de rotação (Horário/Anti-horário).
- Pino 8 (ENABLE): Ativo a nível baixo (LOW). É utilizado para energizar as bobinas do motor, garantindo o binário de retenção ("travão") quando o braço está parado.

Esta arquitetura hierárquica (Raspberry Pi -> Arduino MEGA -> Arduino Uno) assegura que o processamento pesado de imagem não introduz latência na geração dos sinais críticos de controlo dos motores.

## 3.1 Controlo de Baixo Nível (Firmware)

O subsistema de controlo de baixo nível constitui a camada de abstração entre o processamento de imagem (alto nível) e a atuação mecânica. Dada a complexidade cinemática do robô e a necessidade de gerir múltiplos sinais em tempo real, optou-se por uma arquitetura de processamento distribuído.

Ao contrário de uma abordagem centralizada, onde um único processador gere a visão e os motores, este projeto delega as tarefas críticas de temporização (hard real-time) a microcontroladores dedicados (ATmega2560 e ATmega328P). Esta estratégia oferece duas vantagens fundamentais:

1. Estabilidade do Sinal: Garante que a geração de sinais PWM (para os servos) e de pulsos de passo (para a base) não sofre interrupções ou latência devido ao processamento pesado da visão computacional no Raspberry Pi.
2. Modularidade: Permite testar e depurar cada articulação do robô individualmente.

O firmware foi desenvolvido em C++ (ambiente Arduino IDE), implementando uma topologia Mestre-Escravo (Master-Slave), conforme detalhado nas secções seguintes. O Arduino MEGA atua como o controlador central (Mestre), recebendo coordenadas da visão e distribuindo tarefas, enquanto o Arduino Uno atua como um controlador auxiliar (Escravo) dedicado exclusivamente à gestão precisa do motor de passo da base.

### 3.1.1 Subsistema de Controlo da Base (Arduino Uno 'Slave')

Para assegurar o posicionamento preciso do eixo de rotação da base (Yaw), optou-se por uma arquitetura distribuída onde um Arduino Uno opera como unidade secundária (slave). Esta abordagem isola o Arduino MEGA da tarefa de gerar sinais de alta frequência necessários para o controlo do motor de passo.

A. Implementação de Hardware e Potência:

A atuação mecânica é realizada por um motor de passo bipolar (modelo 17HS4401S), gerido através de uma placa de expansão CNC Shield V3. A escolha deste shield oferece vantagens críticas ao projeto:

- Isolamento de Potência: Permite a conexão de uma fonte de alimentação externa dedicada ao motor (12V), separando-a da alimentação lógica do microcontrolador (5V).
- Modularidade e Filtragem: Integra sockets para drivers (utilizou-se o modelo A4988) e condensadores eletrolíticos para estabilização de tensão e supressão do ruído elétrico gerado pela comutação das bobinas.

Interconexões do Sistema: As ligações físicas na placa CNC Shield foram estabelecidas da seguinte forma:

- Eixo X (Motor): O motor de passo conecta-se diretamente à barreira de 4 pinos do driver X.
- Interface de Comunicação: Estabeleceu-se uma ponte UART cruzada, ligando o pino RX do Shield ao TX do Arduino MEGA (e vice-versa), permitindo a receção de comandos.
- Referência Comum (Common Ground): Os pinos GND de ambos os microcontroladores foram interligados para garantir um nível de tensão de referência zero comum, essencial para a estabilidade da comunicação lógica.
B. Lógica de Controlo e Firmware:

O firmware implementado é responsável pela gestão de estados da posição angular (0º, +90º, -90º). O ciclo de funcionamento divide-se em três etapas fundamentais:

### 1. Configuração de Pinos (Setup) Durante a inicialização, os pinos de controlo do driver

A4988 são definidos como saídas digitais, operando com a seguinte lógica:

- ENABLE (Ativação): Opera com lógica inversa. É mantido em estado BAIXO (LOW) para energizar as bobinas e garantir o binário de retenção (holding torque). O estado ALTO (HIGH) desativaria o motor, libertando o eixo.
- DIR (Direção): Sinal binário que determina o sentido de rotação. A alternância entre HIGH e LOW inverte a sequência de energização das fases.
- STEP (Passo): Responsável pela execução do movimento discreto. Cada transição ascendente (de LOW para HIGH) resulta no avanço de um passo mecânico (1.8º).
2. Processamento e Decisão O sistema monitoriza continuamente o buffer da porta série. Ao detetar um comando válido ('0', '1' ou '2'), o algoritmo compara o valor recebido com a variável global posicaoAtual. Se houver divergência, calcula o diferencial de passos e define o estado do pino DIR para a rotação correta.

### 3. Atuação (Geração de Sinal) A função moveMotor() converte a decisão lógica em

movimento físico, gerando uma onda quadrada no pino STEP. A velocidade angular é
controlada | com precisão através de | um | atraso de 500 microssegundos
(delayMicroseconds) entre as transições de estado, garantindo um movimento suave e sem perda de passos.

(O código-fonte completo deste módulo encontra-se disponível no Anexo A).

### 3.1.2 Lógica de Controlo do Braço (Arduino MEGA 2560)

Arduino MEGA 2560 assume o papel de coordenador central do movimento robótico. Diferindo do Raspberry Pi (focado na visão computacional) e do Arduino Uno (dedicado ao motor de passo), este microcontrolador é responsável pela gestão simultânea de múltiplos protocolos de comunicação. O seu ciclo de funcionamento baseia-se em três etapas fundamentais:

### 1. Gestão do Buffer Série O processador monitoriza a porta Série 1 (HardwareSerial)

aguardando a receção do marcador de início ($). Após a deteção, os bytes subsequentes são armazenados num buffer de memória até ser encontrado o marcador de fim (\n). Este mecanismo de validação previne a execução de comandos incompletos ou corrompidos, assegurando a integridade da operação.

### 2. Parsing (Interpretação de Dados) A cadeia de caracteres recebida (ex:

"1,0,180,0,180...") é fragmentada utilizando a vírgula como delimitador. Os valores textuais extraídos são convertidos em números inteiros, representando os ângulos ou estados lógicos desejados para cada atuador.

### 3. Mapeamento e Atuação I2C Os valores angulares (0º a 180º) não são enviados

diretamente para os servomotores. O Arduino converte estes valores em largura de pulso PWM (tipicamente mapeados entre 150 e 600 unidades discretas para o contador de 12-bits). Estes dados são posteriormente transmitidos via barramento I2C para o módulo controlador PCA9685.

O código-fonte completo desenvolvido para o Arduino MEGA encontra-se disponível no Anexo C.

Controlador PWM/Servo (PCA9685)

Para o controlo dos servomotores, recorreu-se à utilização do módulo PCA9685. Este driver de 16 canais permite a alimentação externa dos servos (isolando a carga de potência do microcontrolador) e utiliza uma interface I2C para o comando preciso dos sinais PWM. O esquema de pinagem (pinout) do PCA9685 encontra-se disponível no Anexo 2.

Interconexões do Sistema: As ligações efetuadas entre o módulo e o Arduino MEGA foram as seguintes:

- VCC: Ligado a 5V (Alimentação lógica).
- GND: Ligado ao Ground (Terra comum).
- SDA: Ligado ao pino SDA (Pino 20 no MEGA).
- SCL: Ligado ao pino SCL (Pino 21 no MEGA).

### 3.1.3 Protocolo de Comunicação UART

O estabelecimento da comunicação entre a unidade de processamento de imagem (Raspberry Pi) e o controlador central (Arduino MEGA) é concretizado através do protocolo UART (Universal Asynchronous Receiver-Transmitter), mediante a interligação física dos pinos de transmissão (TX) e receção (RX).

Neste processo, é transmitida continuamente uma cadeia de caracteres (string) formatada, contendo as instruções de controlo. De forma a garantir a sincronização e integridade dos dados, cada mensagem é encapsulada por um marcador de início ($) e um terminador de fim de linha (\n). A trama de dados é composta por 8 parâmetros separados por vírgulas.

Estrutura da Trama de Dados:

$<Orientação>,<Flexão>,<D1>,<D2>,<D3>,<D4>,<D5>,<Rotação>\n

Legenda dos Parâmetros:

- Orientação (Base): Valor inteiro (0, 1 ou 2) para controlo do motor de passo.
- Flexão (Cotovelo): Estado binário (0 ou 1) para extensão ou flexão.
- D1 a D5: Estado binário (0 ou 1) correspondente aos dedos (Indicador, Médio, Anelar, Mínimo e Polegar).
- Rotação: Valor analógico (0 a 180) correspondente ao ângulo do servo de rotação do pulso.

Exemplo de Comando:

- $1,0,1,1,1,1,1,90\n (Interpretação: Base ao centro, Cotovelo estendido, Todos os dedos fechados, Pulso rodado a 90 graus).

Processamento de Dados (Parsing): Do lado do recetor (Arduino MEGA), foi implementado um parser (analisador sintático) que monitoriza o buffer de entrada. O algoritmo aguarda a deteção do marcador $, procedendo à leitura da string até encontrar o terminador \n. Subsequentemente, os valores são segmentados com base no delimitador (vírgula) para distribuição pelos respetivos atuadores. Esta abordagem assegura que apenas pacotes de dados completos são processados, incrementando a robustez do sistema.

# 4 Sistema de Visão Computacional

O subsistema de visão computacional constitui a camada de inteligência do projeto, atuando como o elemento primário de interação homem-máquina (HMI). Ao substituir controladores físicos tradicionais (como joysticks ou botões) por algoritmos de reconhecimento gestual, este módulo permite uma operação intuitiva e sem contacto (contactless).

O presente capítulo descreve a arquitetura de software desenvolvida para o Raspberry Pi 5, fundamentando a seleção da framework MediaPipe para a extração de esqueleto humano. Serão detalhados os desafios de processamento em tempo real, a fundamentação matemática para o cálculo de ângulos articulares e a lógica de conversão destes dados em comandos de atuação mecânica.

## 4.1 Plataforma de Processamento

O núcleo computacional do sistema de visão artificial baseia-se no Single Board Computer (SBC) Raspberry Pi 5. A seleção desta plataforma foi determinante, pois a execução de modelos de Deep Learning em tempo real exige uma capacidade de processamento vetorial significativamente superior à dos microcontroladores convencionais.

Hardware Utilizado: Optou-se pela versão de 8GB de RAM do Raspberry Pi 5, equipada com o processador Broadcom BCM2712 (Arm Cortex-A76 quad-core a 2.4GHz). Esta especificação garante a fluidez necessária (15-20 FPS) para a inferência simultânea dos modelos de mãos e postura corporal.

Acesso Remoto e Telemetria (Headless): Para garantir a portabilidade do robô e eliminar a necessidade de monitores ou periféricos físicos acoplados à estrutura, o sistema opera em modo headless. A interface de visualização e debug é acedida remotamente através do serviço Raspberry Pi Connect. A conexão de rede é estabelecida via Hotspot Móvel 5G, uma escolha estratégica para minimizar a latência de vídeo e garantir uma largura de banda estável, contornando as flutuações e restrições de segurança típicas de redes Wi-Fi locais partilhadas.

Interface de Comunicação (Hardware UART): Diferenciando-se das abordagens convencionais que utilizam cabos USB para comunicação série, este projeto implementa uma ligação direta ao nível do barramento. A transmissão de dados para o controlador utiliza a porta UART (Universal Asynchronous Receiver-Transmitter) dos pinos GPIO:

- Ligação Física: O pino TX (GPIO 14) do Raspberry Pi conecta-se diretamente ao pino RX do Arduino MEGA.
- Vantagem Técnica: Esta topologia elimina a overhead do protocolo USB e a necessidade de conversores USB-Série externos, reduzindo a latência de envio dos pacotes de comando e simplificando a cablagem interna do robô.

Ambiente de Software: O sistema corre sobre o Raspberry Pi OS (Bookworm) 64-bit, utilizando Python 3 e as bibliotecas OpenCV e MediaPipe para o processamento visual, e PySerial para a gestão do fluxo de dados na porta UART.

## 4.2 Fluxograma do Software

Mostra como o código pensa.

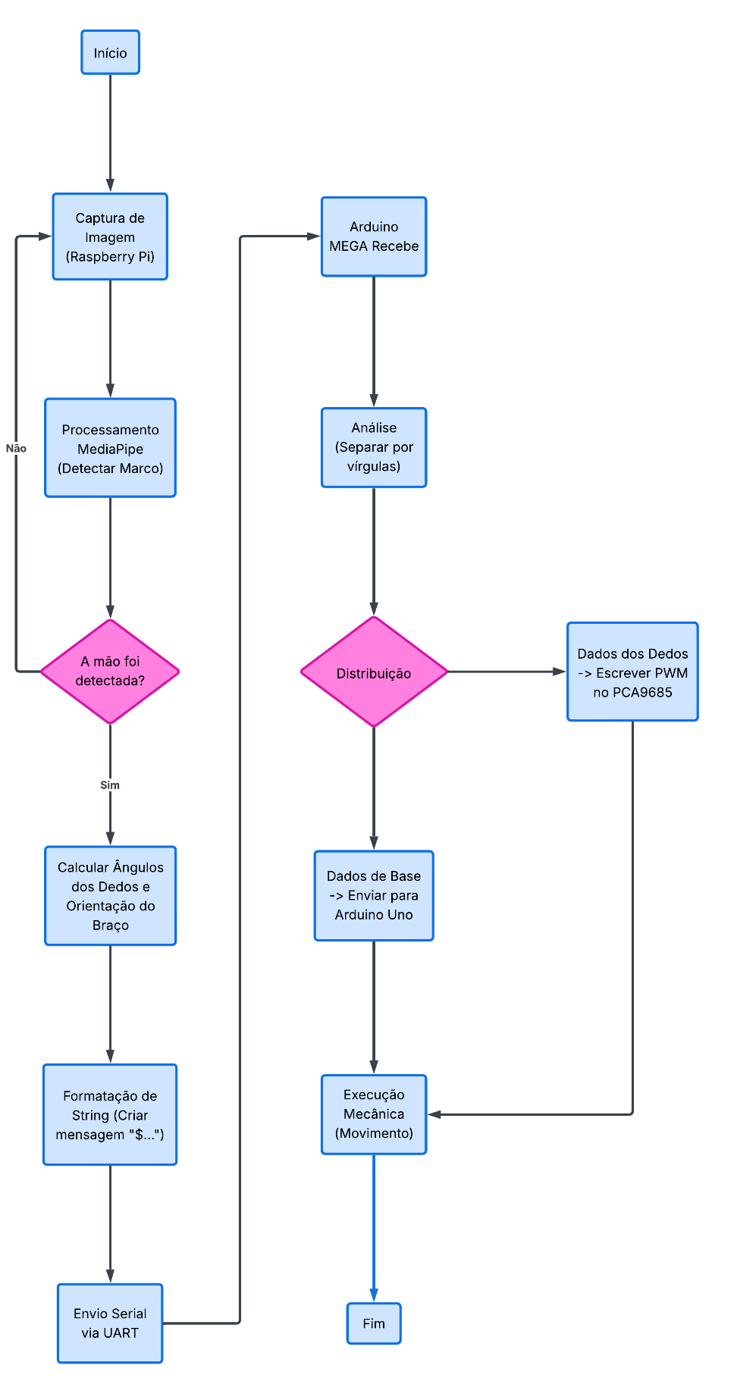
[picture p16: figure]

Figura 13: Fluxograma

## 4.3 Seleção da Ferramenta: Framework MediaPipe

Para a tarefa de deteção e rastreamento da mão e postura corporal, optou-se pela utilização do MediaPipe, uma framework de código aberto desenvolvida pela Google.

A escolha do MediaPipe, em detrimento de redes neuronais convolucionais (CNNs) tradicionais (como YOLO ou SSD) treinadas para deteção de objetos, justifica-se pela sua arquitetura otimizada para inferência em hardware com recursos limitados (CPU). Enquanto uma CNN típica processa toda a imagem a cada frame para encontrar uma "caixa delimitadora" (bounding box) à volta da mão, o MediaPipe utiliza uma abordagem em duas etapas:

1. Deteção de Palma: Um modelo leve localiza a mão na imagem inicial.
2. Regressão de Landmarks: Uma vez localizada a mão, um segundo modelo mais complexo estima a posição de 21 pontos esqueléticos 3D (designados por landmarks) dentro dessa região, sem necessidade de reprocessar a imagem inteira.

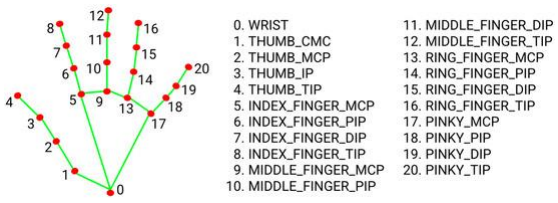
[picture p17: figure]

Figura 14: Topologia dos 21 landmarks detetados pelo modelo MediaPipe Hands.

Esta abordagem permite atingir taxas de atualização elevadas (aproximadamente 20 FPS no Raspberry Pi 5), essenciais para um controlo robótico fluido e em tempo real. Foram utilizados dois módulos específicos:

- MediaPipe Hands: Para a deteção detalhada dos 21 pontos das articulações dos dedos e pulso (Figura 15).
- MediaPipe Pose: Para a deteção da postura superior do corpo, especificamente os pontos dos ombros, utilizado para controlar a rotação da base (Figura 16).

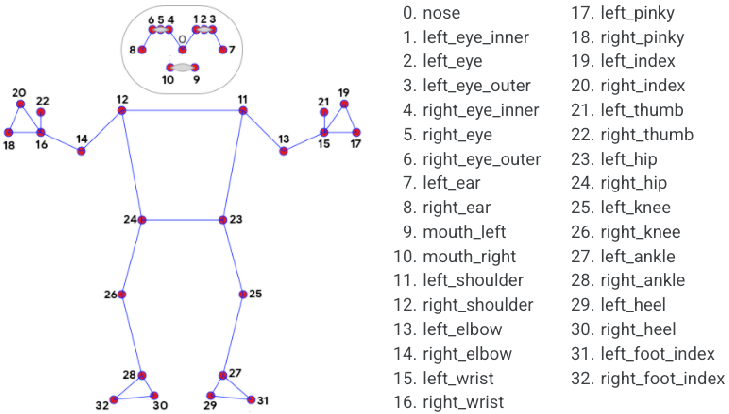
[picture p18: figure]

Figura 15: Mapeamento dos landmarks corporais do modelo MediaPipe Pose.

A visualização destes pontos pode ser observada na Figura 16. As linhas azuis representam as conexões esqueléticas da mão detetada pelo módulo Hands, enquanto a linha verde horizontal no topo representa a conexão entre os ombros detetada pelo módulo Pose.

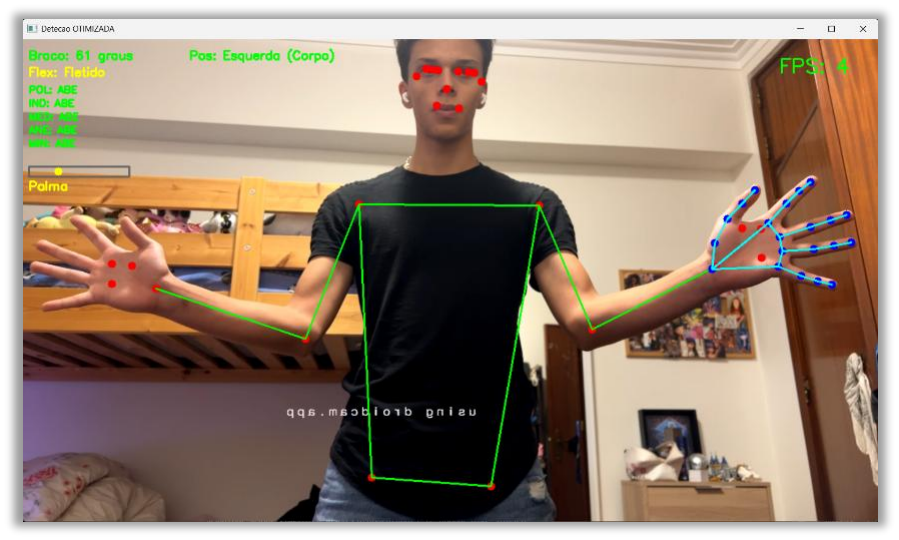
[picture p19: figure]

Figura 16: Visualização em tempo real das landmarks detetadas.

## 4.4 Metodologia de Desenvolvimento (PC vs. Raspberry Pi)

Devido à complexidade dos cálculos geométricos e à necessidade de calibração fina dos limiares (thresholds) de deteção, o desenvolvimento do software seguiu uma abordagem faseada.

Inicialmente, o algoritmo foi integralmente desenvolvido e testado num computador pessoal (PC) com maior poder de processamento. Foi criado um script de depuração dedicado (VisionDebugger_PC.py) que permite visualizar os ângulos calculados em tempo real no ecrã, facilitando o ajuste dos parâmetros sem a latência inerente ao hardware embarcado. Apenas após a validação robusta dos algoritmos, o código foi migrado e otimizado para o ambiente Linux do Raspberry Pi 5, garantindo uma transição suave do ambiente de desenvolvimento para o de produção.

## 4.5 Aquisição de Imagem e Multithreading

Para maximizar o desempenho, a captura de vídeo foi dissociada do processamento principal. Implementou-se uma classe dedicada (FluxoCamera no código) que utiliza multithreading. Um processo independente é responsável por ler os frames da câmara (utilizando a biblioteca OpenCV) e colocá-los num buffer. O ciclo principal do programa lê sempre o frame mais recente disponível neste buffer.

Esta técnica evita que o tempo de processamento da IA e dos cálculos matemáticos bloqueie a leitura da câmara, reduzindo significativamente a latência total do sistema.

## 4.6 Lógica de Controlo e Utilização de Landmarks

A tradução dos movimentos humanos para o robô baseia-se na análise geométrica dos landmarks fornecidos pelo MediaPipe. O sistema processa dois fluxos de dados distintos, visualizados na interface de depuração (Figura 17): as linhas de conexão verdes correspondem ao esqueleto corporal (MediaPipe Pose) e as linhas azuis correspondem à estrutura da mão (MediaPipe Hands).

Embora o MediaPipe forneça 21 pontos por mão, não é necessário utilizar todos para determinar o estado básico de preensão. Foram selecionados pontos estratégicos para reduzir a carga computacional.

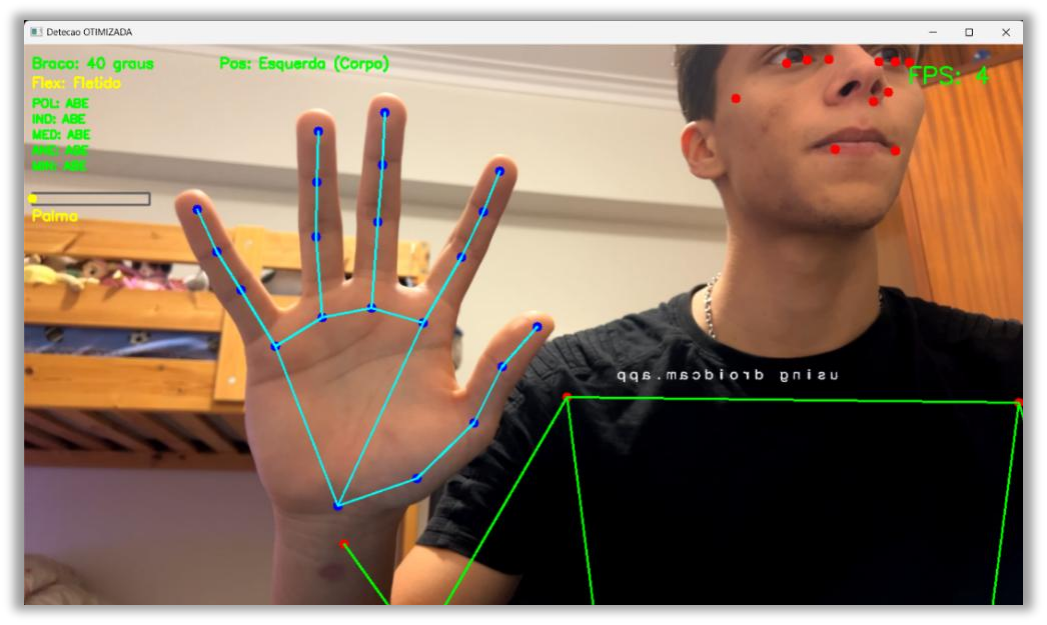
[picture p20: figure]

Figura 17: Interface de depuração em funcionamento

### 4.6.1 Fundamentação Matemática: Cálculo de Ângulos Articulares

Uma das decisões críticas do projeto foi não basear o estado dos dedos ("aberto" ou "fechado") na simples distância euclidiana entre a ponta do dedo e o pulso. Este método é falível, pois varia consoante a proximidade da mão à câmara (escala).

Em vez disso, optou-se por uma abordagem baseada na geometria vetorial, calculando o ângulo formado pelas articulações. Este método é invariante à escala e à rotação da mão. Para determinar o estado de um dedo, calcula-se o ângulo θ no vértice formado por três pontos-chave: a base do dedo (A), a articulação intermédia (B) e a ponta do dedo (C).

A função angulo_3pts, implementada no código, utiliza o produto escalar entre dois vetores (BA e BC) e a função arco-cosseno para determinar este ângulo:

θ = arccos(

BA ∗ BC
|BA||BC|

)

O seguinte trecho de código ilustra a implementação desta função utilizando a biblioteca Math para eficiência vetorial:

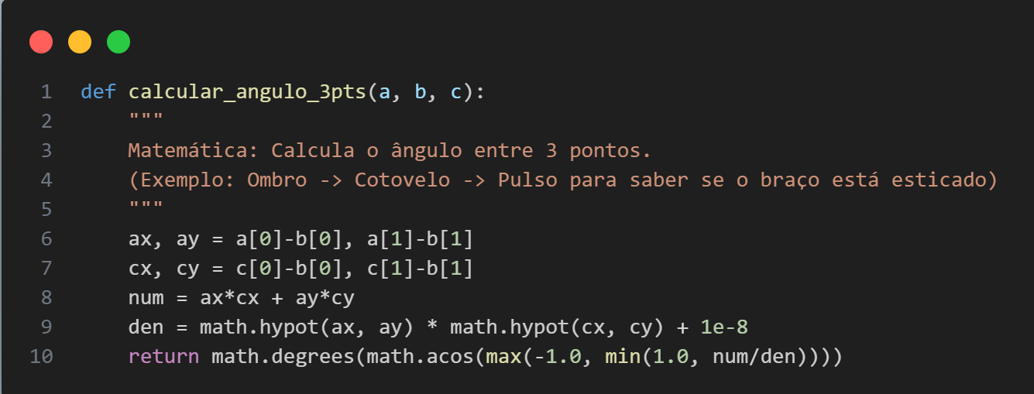
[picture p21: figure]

### 4.6.2 Estado dos Dedos (Aberto/Fechado)

Para determinar se um dedo se encontra fletido ou estendido, não se utiliza a distância entre pontos (que varia com a profundidade), mas sim o cálculo vetorial do ângulo na articulação intermédia.

Tomando como exemplo o dedo indicador, o algoritmo seleciona três pontos chave definidos no dicionário FINGERS do código:

- Ponto 5 (MCP): Articulação da base (referência proximal).
- Ponto 6 (PIP): Articulação intermédia (o vértice do ângulo).
- Ponto 8 (TIP): Ponta do dedo.

A função angulo_3pts calcula o ângulo "θ" (teta) no vértice (Ponto 6) através do produto escalar dos vetores formados pelos segmentos de reta entre os pontos.

- Lógica: Se o ângulo θ for superior a TH_INDICADOR (ex: 160º), o dedo considera-se Aberto. Caso contrário, considera-se Fechado. Esta lógica replica-se para os cinco dedos, garantindo robustez independentemente da rotação da mão.

Esta configuração repete-se para os restantes dedos, conforme o dicionário implementado no software:

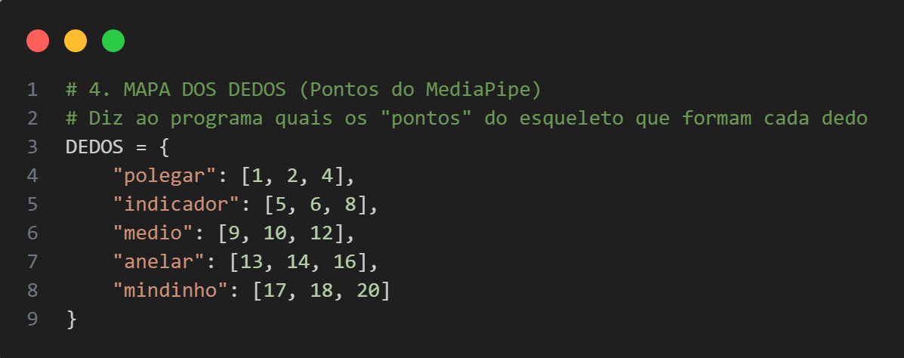
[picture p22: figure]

### 4.6.3 Controlo da Base e Cotovelo (Direita / Centro / Esquerda)

Para a determinação da Orientação da Base (controlar se o robô roda para a esquerda, direita ou fica ao centro), o algoritmo não segue a posição X da mão na imagem (o que seria instável), mas sim a abertura do braço (ângulo do cotovelo).

Conforme | o | código | desenvolvido | (VisionDebugger_PC_PT.py) | na | função
determinar_orientacao_braco e a topologia do MediaPipe Pose (Figura 16), os pontos utilizados são:

Se for detetado o lado Direito do utilizador (padrão):

- Ponto 12 (Ombro Esquerdo/Direito na imagem): Ponto de âncora proximal.
- Ponto 14 (Cotovelo): O Vértice onde é calculado o ângulo.
- Ponto 16 (Pulso): O ponto móvel que define a extensão.

(Nota: Se o sistema detetar o outro braço, usa os pontos simétricos: 11, 13 e 15).

Como funciona o cálculo: O software calcula o ângulo formado no Cotovelo (Ponto 14) entre o segmento do Ombro e o segmento do Pulso.

- Braço Fechado (< 70º): O sistema interpreta como comando "Esquerda".
- Braço Aberto (> 130º): O sistema interpreta como comando "Direita".
- Intermédio: O sistema mantém-se no "Centro".

Isto permite controlar a base apenas esticando ou recolhendo o braço, sem precisar de deslocar o corpo pela sala.

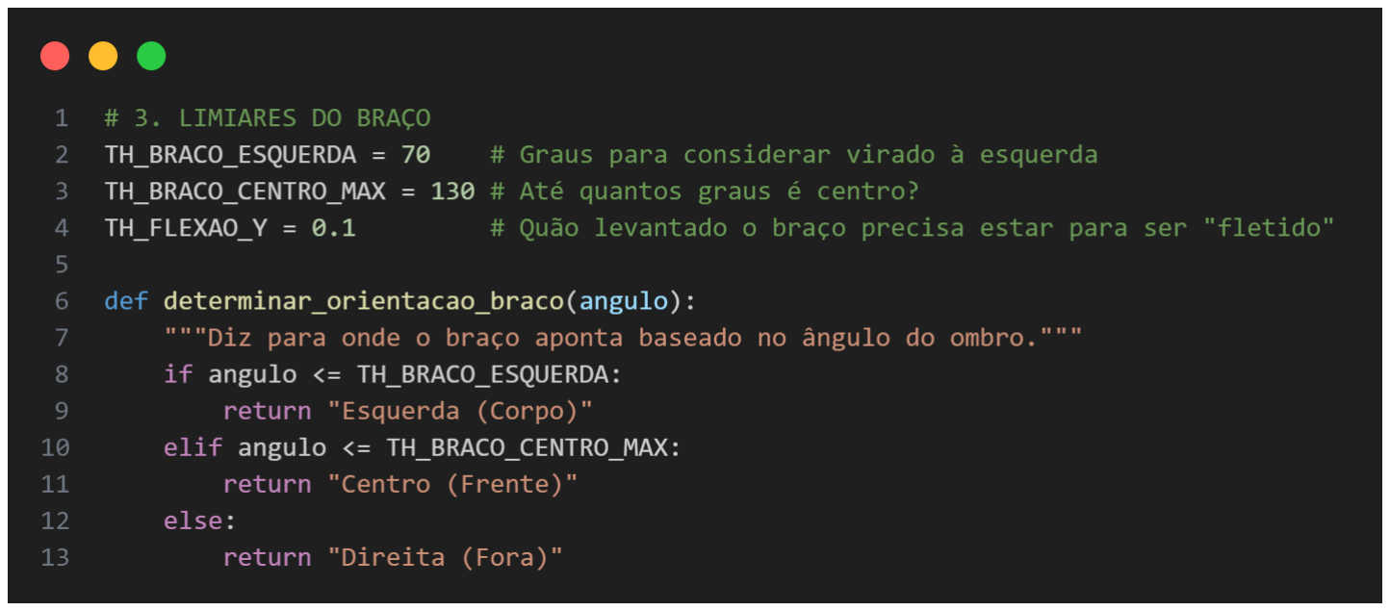
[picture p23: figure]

### 4.6.4 Flexão do Cotovelo (Cima / Baixo)

Para a Flexão do Cotovelo (Movimento Cima / Baixo - Pitch), o algoritmo não utiliza ângulos, mas sim a diferença de altura (coordenada Y) entre dois pontos específicos para determinar a intenção do operador.

Conforme a implementação na função determinar_flexao_braco no ficheiro VisionDebugger_PC_PT.py e o mapa corporal na Figura 16, os pontos utilizados são:

- Ponto 11 ou 12 (Ombro): Serve como ponto de referência estático (altura base).
- Ponto 15 ou 16 (Pulso): Serve como ponto móvel.

Lógica de Funcionamento:

O sistema calcula a distância vertical absoluta entre o ombro e o pulso:

ΔY = |Y_ombro - Y_pulso|

- Ao contrário da rotação da base (que usa 3 pontos para um ângulo), aqui compara-se apenas a posição relativa vertical do pulso em relação ao ombro.

- Se o pulso estiver muito abaixo do ombro (grande diferença em Y), o braço está "em baixo".
- Se o pulso subir e se alinhar com o ombro (pequena diferença em Y), o sistema deteta a elevação.

### 4.6.5 Rotação do Pulso (Roll)

Visto que o MediaPipe não fornece nativamente o ângulo de Roll (rotação da palma), foi desenvolvido um algoritmo heurístico na função calcular_rotacao_mao. Este método compara a posição relativa da ponta do Polegar (Ponto 4) e do Dedo Mínimo (Ponto 20).

A inovação deste algoritmo reside na troca dinâmica de eixos:

- Caso A (Braço Fletido): A rotação é calculada pela diferença no Eixo X (horizontal) entre o polegar e o mínimo.
- Caso B (Braço Estendido): A rotação é calculada pela diferença no Eixo Y (vertical).

O valor diferencial resultante é normalizado num intervalo de -1 a 1 e mapeado para o intervalo de 0º a 180º, permitindo que o servo da rotação copie o movimento natural da mão do operador, quer este esteja com o braço levantado ou em baixo.

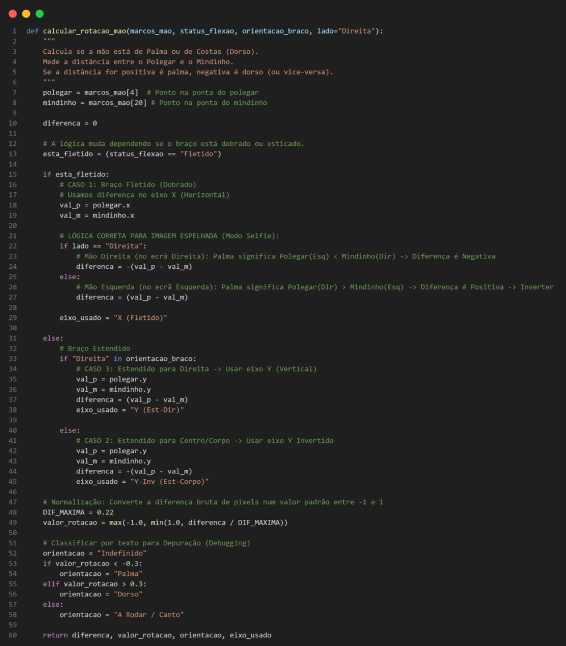
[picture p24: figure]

# 5 Resultados

A fase final do projeto consistiu na integração dos subsistemas de visão computacional, controlo lógico e mecânica. Os testes realizados validaram a arquitetura do sistema, embora tenham sido identificados desvios face ao desenho teórico inicial.

## 5.1 Resultados da Construção

Após a conclusão dos ciclos de impressão, procedeu-se à remoção das estruturas de suporte e à limpeza de todos os componentes (rebarbamento). Nesta fase, foi realizada uma inspeção visual rigorosa para validar a integridade estrutural das peças e a aderência entre camadas, garantindo que não existiam deformações críticas que comprometessem a montagem mecânica. A Figura 2 ilustra o conjunto completo de peças preparadas para a fase de assemblagem, dispostas para inventariação.

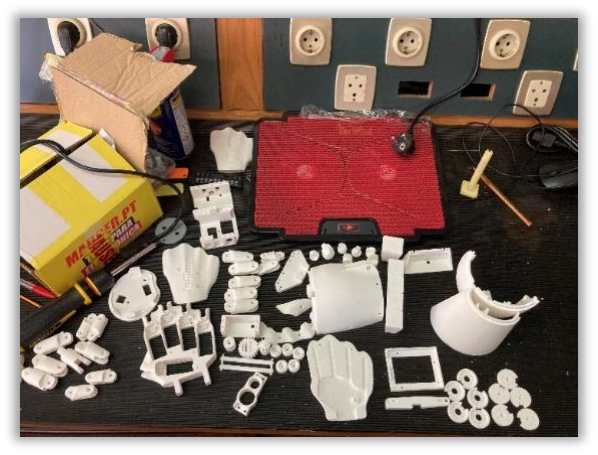
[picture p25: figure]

Figura 18: Conjunto de componentes estruturais do braço produzidos em PLA.

Seguidamente, iniciou-se a pré-montagem estrutural do braço e da mão, ainda sem a integração dos atuadores (servomotores) e da cablagem. Esta etapa intermédia foi fundamental para verificar as tolerâncias dimensionais e o correto acoplamento entre as juntas rotativas e as peças estáticas.

Como se pode observar na Figura 3, o modelo InMoov demonstrou uma boa estabilidade mecânica apenas com as conexões estruturais, validando a qualidade da impressão 3D em PLA. Nesta configuração, confirmou-se a liberdade de movimento dos dedos e do pulso antes da fixação definitiva dos componentes eletrónicos.

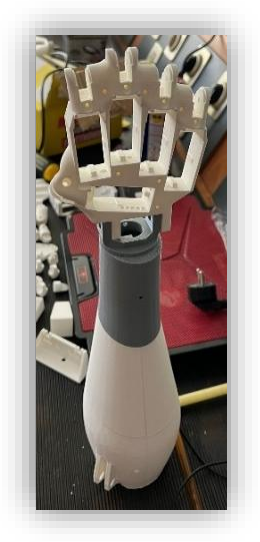
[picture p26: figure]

Figura 19: Vista geral do sistema robótico parcialmente montado.

A montagem física do robô, baseada na manufatura aditiva (Impressão 3D em PLA), revelou desafios de tolerância e ajuste que exigiram intervenções corretivas durante a fase de construção:

- Incompatibilidades Geométricas: Na montagem da estrutura de suporte, verificou-se uma interferência entre a cabeça dos parafusos de fixação e a superfície de contacto entre a Base do Braço Superior (Fig. 9) e a Base do Braço Inferior (Fig. 8). Foi necessário realizar um pós-processamento manual (desbaste de material) para garantir o nivelamento e o acoplamento correto das peças.
- Resistência Estrutural e Tolerâncias: Durante a inserção do rolamento mecânico na Estrutura Principal (Fig. 5), observou-se uma fratura nas extremidades do componente impresso. Esta falha resultou de um ajuste de interferência excessivo para a rigidez do PLA, agravado pelas tensões internas do material arrefecido. A peça foi recuperada através de reforço estrutural localizado, permitindo a continuidade dos ensaios.

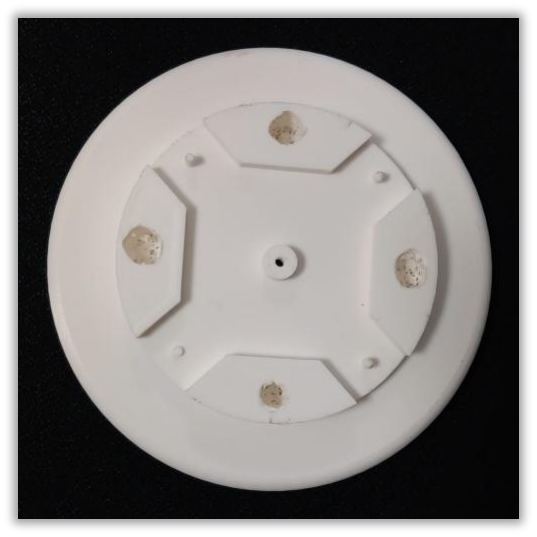
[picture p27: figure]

Figura 20: Componente da base superior do braço sujeito a alterações pós-impressão.

## 5.2 Validação da Visão Computacional

A fase final do projeto consistiu na integração total dos subsistemas de visão computacional, processamento lógico e atuação mecânica. Os testes realizados em ambiente real demonstraram o sucesso da arquitetura distribuída (Raspberry Pi + Arduinos), validando a capacidade do braço robótico em mimetizar os movimentos humanos com elevada fidelidade.

Conforme ilustrado na Figura 19, o sistema operou de forma autónoma, traduzindo a detecção dos landmarks faciais e manuais em comandos mecânicos precisos.

Análise de Desempenho:

1. Tempo de Resposta (Latência): O sistema de visão, a correr no Raspberry Pi 5, manteve uma taxa de atualização estável (entre 15 a 20 FPS). A latência entre o gesto do operador e o movimento do servomotor foi percetível, mas reduzida o suficiente para ser considerada "tempo real" para aplicações de telepresença.
2. Precisão da Mimetização:
- Dedos: O algoritmo vetorial (baseado em ângulos) provou ser robusto, ignorando falsos positivos causados pela rotação da mão ou variação da distância à câmara.
- Base e Cotovelo: A lógica de controlo gestual (baseada na extensão do braço e altura do pulso) permitiu controlar os motores de maior carga de forma intuitiva, sem exigir que o operador se deslocasse fisicamente da frente da câmara.
3. Estabilidade Mecânica: O protocolo de comunicação UART implementado garantiu que não existissem perdas de pacotes de dados, resultando num movimento fluido, embora limitado pelas restrições mecânicas dos próprios servomotores (velocidade de rotação e binário).

Em suma, a demonstração visual (Figura 19) comprova que o sistema atingiu os objetivos propostos: uma interface natural "humano-máquina" onde o corpo do operador funciona como o próprio comando do robô.

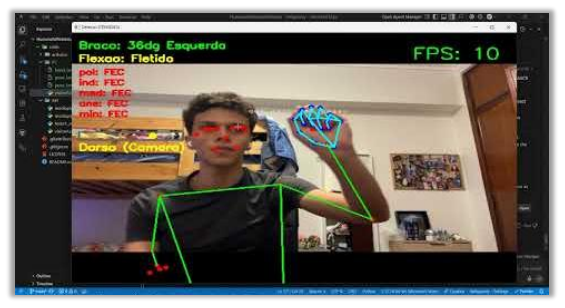
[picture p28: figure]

Figura 21: Demonstração funcional do sistema integrado

O desenvolvimento do módulo de visão computacional representou o desafio lógico mais complexo do projeto, constituindo a camada de abstração que permite a interação natural entre o operador humano e o sistema robótico.

A opção pela framework MediaPipe revelou-se acertada para a arquitetura de hardware limitada do Raspberry Pi 5. Ao contrário de redes neuronais de deteção de objetos convencionais (como YOLO), a abordagem baseada em landmarks esqueléticos permitiu manter uma taxa de processamento elevada (aproximadamente 20 FPS), garantindo uma latência mínima crítica para aplicações de telepresença.

Do ponto de vista algorítmico, conclui-se que a transição de uma lógica baseada em distâncias euclidianas para uma baseada em geometria vetorial foi determinante para a robustez do sistema. O cálculo de ângulos articulares tornou o controlo invariante à escala, permitindo que o sistema funcione corretamente e independentemente da distância do utilizador à câmara. Adicionalmente, a implementação de heurísticas dinâmicas — como a troca de eixos para o cálculo da rotação do pulso e a máquina de estados para o controlo da base — permitiu contornar as limitações de um sistema de câmara monocular (2D), inferindo comportamentos tridimensionais complexos.

Em suma, o software desenvolvido não se limita a detetar a mão, mas atua como um intérprete de intenções, convertendo dados visuais brutos em comandos determinísticos prontos a serem transmitidos ao controlador de baixo nível (Arduino).

## 5.3 Validação Funcional (Mimetização)

O sistema atingiu o seu objetivo primário: a tradução de gestos humanos em movimentos robóticos. Conforme demonstrado na Figura X (registo vídeo dos testes), o braço robótico foi capaz de replicar a postura do operador em tempo real.

Os resultados da visão computacional indicaram uma taxa de atualização estável (aprox. 20 FPS no Raspberry Pi), permitindo uma latência "movimento-ação" suficientemente baixa para criar uma sensação de controlo direto. Os algoritmos vetoriais de deteção dos dedos mostraram-se robustos, acionando os servomotores corretamente mesmo com variações na iluminação ambiente.

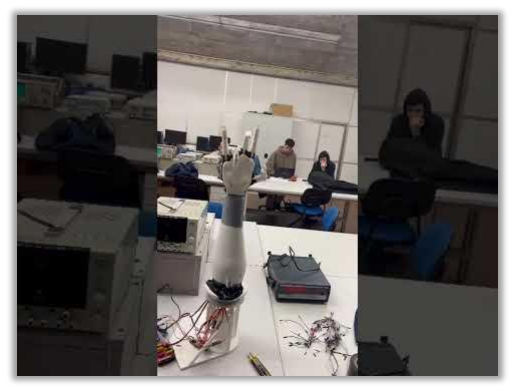
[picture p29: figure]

Figura 22: Sequência de teste funcional em tempo real.

## 5.4 Desvios ao Projeto Inicial

Embora a funcionalidade principal tenha sido assegurada, o protótipo final apresenta limitações face à especificação idealizada:

- Graus de Liberdade (DoF): Não foi concretizada a implementação do servomotor adicional responsável pela inclinação frontal do ombro (Forward Pitch). Desta forma, a cinemática do braço ficou restrita à rotação da base, elevação lateral do ombro, rotação do pulso e actuação dos dedos.
- Estabilidade da Instalação: A fixação da base robótica à bancada de testes foi realizada através de métodos provisórios (adesivos temporários), o que resultou numa menor estabilidade face a movimentos de inércia elevada. Adicionalmente, a câmara de visão não possui um suporte solidário à estrutura do robô, tornando o sistema suscetível a desalinhamentos caso ocorram choques acidentais na mesa de trabalho, exigindo recalibrações da posição do operador.

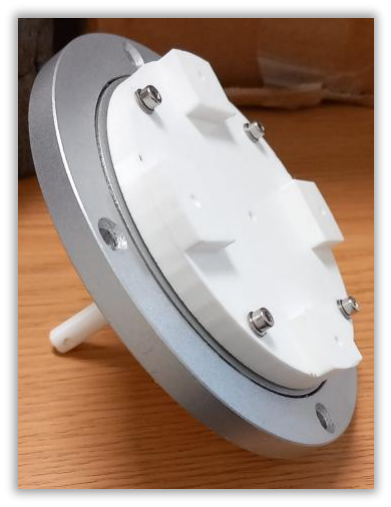
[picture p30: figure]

Figura 23: Mecanismo de acoplamento da base superior.

## 5.5 Lista de Material Final

Nome | Referência/Especificação | Quantidade | Preço
Molas | 3/16″x1-3/4 or 4.8mm x 44.5mm | 5 molas (total) | 7.49€
Tubos | Teflon pipes ID1.5MM X OD2.5MM | 1595mm | 2€
Servo motores (dedos) | MG996R | 6 | 8.90€
Servo motores (braço) | DS5160 | 1 | emStock
Motor de passo (base) | 17HS4401S | 1 | emStock
Tendões | braided fishing line 0.8mm 200LB | 5x50cm | 8.12
Cabo Eletronico | | 16x40cm | em stock
Ecoflex | RTV silicone Ecoflex™ 00-10 | 1 | 35.00€
Câmera | Raspberry Pi Module 3 | 1 | emStock
Raspberry PI 5 | Raspberry PI 5 | 1 | emStock
Arduino MEGA | Arduino MEGA | 1 | emStock
Arduino Uno | Arduino Uno | 1 | emStock
CNC Shield | CNC Shield V3 | 1 | emStock
Manga Termo Retráctil | | 1.2m ou 800pz | 3.51€
Íman | Ø 2.5 mm, altura 1 mm | 5 | 4.6
Fluxo RMA | 096-0207 | 1 | 1.99
Fita em poliamida | 095-0793 | 1 | 5.03
Cabo Unifilar | | | 4.49€

Tabela 4: Lista de Material

"Numa primeira abordagem, privilegiou-se a adesão à lista de materiais especificada no guia de referência [2]. No entanto, constatou-se que diversos componentes se encontravam descontinuados comercialmente e que as referências originais (links) estavam obsoletas.

Face a esta limitação, procedeu-se à elaboração de uma nova lista de materiais [Tabela 3], ajustada aos requisitos específicos do projeto. Relativamente aos componentes não disponíveis no stock da instituição, foi realizado um estudo de mercado com o objetivo

# 6 Conclusões e Trabalho Futuro

A realização deste projeto culminou no desenvolvimento de um sistema robótico antropomórfico funcional, capaz de validar a integração complexa entre fabrico aditivo, eletrónica de controlo distribuída e visão computacional. O protótipo final atingiu o objetivo primordial de mimetização, demonstrando que é possível criar interfaces humano-máquina intuitivas e de baixo custo utilizando tecnologias acessíveis como o Raspberry Pi e o MediaPipe.

No entanto, a análise crítica dos resultados experimentais permitiu identificar áreas onde a implementação atual, embora funcional, pode evoluir para um sistema de maior fidelidade e robustez.

## 6.1 Propostas de Trabalho Futuro

Com o intuito de aproximar o protótipo de uma aplicação profissional de telepresença, sugerem-se as seguintes linhas de investigação e desenvolvimento:

### 1. Implementação de Controlo Proporcional (Mimetização Analógica) A limitação

mais significativa do software atual reside na natureza discreta (binária ou por estados) dos movimentos. O sistema deteta apenas se um dedo está "Aberto" ou "Fechado", ou se o braço está na "Esquerda" ou "Direita".

- Melhoria Proposta: Evoluir os algoritmos de visão para um mapeamento proporcional direto. Em vez de comparar ângulos com um limiar fixo, o sistema deverá converter o ângulo de flexão do dedo do operador (ex: 45º) diretamente num valor PWM correspondente para o servo (ex: servo.write(90)). Esta lógica deve ser estendida à rotação da base e à flexão do cotovelo, permitindo que o robô copie a velocidade e a posição exata do operador em tempo real, e não apenas salte para posições pré-definidas.

### 2. Evolução da Estrutura Mecânica e Suporte da Câmara A estabilidade física do

sistema carece de otimização. A fixação provisória da base e a independência da câmara revelaram-se pontos fracos durante os testes.

- Melhoria Proposta: Redesenhar a base do robô para incluir um suporte integrado e ajustável para a câmara. Isto garantiria que o referencial de visão fosse sempre solidário ao robô, eliminando a necessidade de recalibração caso o sistema seja movido. Adicionalmente, deve ser desenvolvido um sistema de fixação à bancada por grampos (em vez de adesivos) para suportar a inércia de movimentos rápidos.

### 3. Expansão dos Graus de Liberdade (Cinemática Completa) O modelo atual carece

do movimento de inclinação frontal do ombro (Forward Pitch), o que restringe a área de trabalho manipulável.

- Melhoria Proposta: Concretizar a instalação do servomotor em falta na articulação do ombro e integrar o respetivo controlo na cinemática inversa. Isto permitiria ao braço realizar movimentos de alcance para a frente e para trás, essenciais para agarrar objetos dispostos em diferentes profundidades na mesa.

### 4. Feedback Sensorial (Malha Fechada) Atualmente, o operador não recebe qualquer

retorno físico sobre o sucesso da preensão.

- Melhoria Proposta: Instalar sensores de pressão (FSR) nas pontas dos dedos e motores de vibração numa luva háptica para o operador. Desta forma, quando o robô tocasse num objeto, o utilizador sentiria uma vibração correspondente, fechando o ciclo de controlo e permitindo a manipulação de objetos frágeis com maior segurança.

Em suma, este projeto estabeleceu uma base sólida para o desenvolvimento de robótica assistida, provando que a visão computacional moderna pode substituir controladores físicos complexos, tornando a tecnologia mais natural e acessível ao ser humano.

# 7 Referências

[1] H. Abrantes, C. Rodrigues e R. Maria, "Proposta de Projeto Integrado: Braço Robótico Controlado por Visão", Escola Náutica Infante D. Henrique, Paço de Arcos, 2025.
[2] G. Langevin, "InMoov Hand I2”, InMoov Open-Source 3D Printed Life-Size Robot. [Online]. Disponível: https://inmoov.fr/hand-and-forarm. [Acedido: 28-Nov-2025].
[3] G. Langevin, "InMoov Hand and Forearm”, InMoov Open-Source 3D Printed Life-Size Robot. [Online]. Disponível: https://inmoov.fr/hand-i2. [Acedido: 28-Nov-2025].
[4] Dsservo, "DS5160 Digital Servo Datasheet", 2023. [Online]. Disponível: https://m.media-amazon.com/images/I/81EFGw8qkhL.pdf.
[5] Handson Technology, "17HS4401S Bipolar Stepper Motor Datasheet".
[Online]. | Disponível: | https://www.alldatasheet.com/datasheet-
pdf/view/1492290/ETC/17HS4401S.html. (https://www.google.com/search)
[6] Arduino Forum, "Using CNC Shield V3 directly with Arduino IDE", 2022.
[Online]. | Disponível: | https://forum.arduino.cc/t/using-cnc-shield-v3-
directly-with-arduino-ide/1022999/2. (https://forum.arduino.cc/t/using-cnc-shield-v3-directly-with-arduino-ide/1022999/2)
[7] Google Developers, "MediaPipe Hands," MediaPipe Solutions. [Online]. Disponível:
https://ai.google.dev/edge/mediapipe/solutions/vision/pose_landmarker.
[8] Google Developers, "MediaPipe Pose," MediaPipe Solutions. [Online]. Disponível:
https://developers.google.com/mediapipe/solutions/vision/pose_landmark er. (https://www.google.com/search)
[9] OpenCV Team, "OpenCV: Open-Source Computer Vision Library," 2024. [Online]. Disponível: https://opencv.org/.
[10] Raspberry Pi Foundation, "Raspberry Pi 5 – Documentation and Hardware
Specifications," | 2024. | [Online]. | Disponível:
https://www.raspberrypi.com/documentation/computers/raspberrypi.html. (https://www.raspberrypi.com/documentation/computers/raspberry-pi.html)

[11] Arduino, "Arduino Mega 2560 Rev3 Datasheet & Pinout". [Online]. Disponível: https://docs.arduino.cc/hardware/mega-2560.
[12] Protoneer, "Arduino CNC Shield V3.00 – Schematics and Pinout," 2022.
[Online]. | Disponível: | https://www.zyltech.com/arduino-cnc-shield-
instructions/. (https://www.zyltech.com/arduino-cnc-shield-instructions/)
[13] Grupo RIA-G7, "Repositório de Código Fonte: Humanoid Robotic Arm
Vision | Control," | GitHub, | 2025. | [Online]. | Disponível:
https://github.com/Bolofofopt/HumanoidRoboticArmVision.
[14] Grupo RIA-G7, "Esquema Elétrico Completo e Interativo - Braço Robótico," Cirkit Designer Project, 2025. [Online]. Disponível: https://app.cirkitdesigner.com/project/.

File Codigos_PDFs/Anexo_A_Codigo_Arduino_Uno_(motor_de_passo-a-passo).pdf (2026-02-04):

// --- Definições de Hardware (CNC Shield - Eixo X) ---
#define STEP_PIN | 2

#define DIR_PIN | 5

#define ENABLE_PIN 8

// --- Definição de Parâmetros Mecânicos ---
// O motor tem 200 passos/volta (1.8 graus/passo).
// Com driver em full-step: 200 passos = 360 graus.
// Se estiver a usar microstepping (ex: 1/16), estes valores devem ser ajustados. const int PASSOS_PARA_90_GRAUS = 800; // Ajustar conforme o microstepping configurado nos jumpers
const int PASSOS_PARA_180_GRAUS = 1600;

// --- Variáveis de Estado --- (FIM DE CURSO POR IMPLEMENTAR) // 0 = Centro (0 graus)
// 1 = Esquerda (+90 graus)
// 2 = Direita (-90 graus)
int posicaoAtual = 0;

void setup() {
// Configuração dos pinos do driver A4988 pinMode(STEP_PIN, OUTPUT); pinMode(DIR_PIN, OUTPUT);
pinMode(ENABLE_PIN, OUTPUT);

// ATIVAÇÃO DO MOTOR:
// O pino Enable é ativo a LOW. Ao colocar LOW, as bobinas são energizadas // e o motor ganha binário de retenção (fica duro). digitalWrite(ENABLE_PIN, LOW);

// Inicia a comunicação Série (UART) com o Arduino MEGA Serial.begin(9600);
}

void loop() {
// Verifica se o Arduino MEGA enviou algum comando if (Serial.available() > 0) {
char comando = Serial.read();

// --- MÁQUINA DE ESTADOS PARA CONTROLO DE POSIÇÃO ---

// CASO 1: Comando para ir ao CENTRO (0)
if (comando == '0' && posicaoAtual != 0) {
if (posicaoAtual == 1) { // Estava em +90 moveMotor(PASSOS_PARA_90_GRAUS, LOW); // Recua 90 }
else if (posicaoAtual == 2) { // Estava em -90 moveMotor(PASSOS_PARA_90_GRAUS, HIGH); // Avança 90 }

posicaoAtual = 0; // Atualiza estado
}

// CASO 2: Comando para ir para ESQUERDA (+90)
else if (comando == '1' && posicaoAtual != 1) {
if (posicaoAtual == 0) { // Estava em 0 moveMotor(PASSOS_PARA_90_GRAUS, HIGH); // Avança 90
}
else if (posicaoAtual == 2) { // Estava em -90 moveMotor(PASSOS_PARA_180_GRAUS, HIGH); // Avança 180 (atravessa o centro) }
posicaoAtual = 1;
}

// CASO 3: Comando para ir para DIREITA (-90)
else if (comando == '2' && posicaoAtual != 2) {
if (posicaoAtual == 0) { // Estava em 0 moveMotor(PASSOS_PARA_90_GRAUS, LOW); // Recua 90 }
else if (posicaoAtual == 1) { // Estava em +90 moveMotor(PASSOS_PARA_180_GRAUS, LOW); // Recua 180 }
posicaoAtual = 2;
}
}
}

// Função auxiliar para gerar os pulsos de passo void moveMotor(int numPassos, bool direcao) { digitalWrite(DIR_PIN, direcao);

for (int x = 0; x < numPassos; x++) { digitalWrite(STEP_PIN, HIGH);
delayMicroseconds(500); // Define a velocidade do motor digitalWrite(STEP_PIN, LOW);
delayMicroseconds(500);
}
}

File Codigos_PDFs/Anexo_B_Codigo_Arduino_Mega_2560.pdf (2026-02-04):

/*
*
================================================================================= =====
* | NOME DO FICHEIRO: MotorDriver_PT.ino
*
================================================================================= =====
*
* DESCRIÇÃO PARA PRINCIPIANTES:
* Este é um programa para um Arduino Mega. O Arduino é como o "cérebro" eletrónico
* que controla o braço robótico.
*
* O que este programa faz:
* 1. Recebe ordens do "cérebro de visão" (o Raspberry Pi ou computador).
* 2. As ordens vêm em forma de mensagem de texto (ex: "$1,0,1,1,1,1,1,90"). * 3. O Arduino lê essa mensagem e traduz para movimentos físicos nos motores. *
* TIPOS DE MOTORES USADOS:
* - Servo Motores (controlados pela placa PCA9685): Usados para os dedos, cotovelo e rotação da mão.
* - Motor de Passo/Stepper (controlado por outro Arduino Uno): Usado para rodar a base do braço.
*
* LINGUAGEM: C++ (Linguagem padrão do Arduino)
*
================================================================================= =====
*/

// --- BIBLIOTECAS (Livrarias de código) ---
// Estas linhas "chamam" código extra que já foi escrito por outras pessoas // para nos ajudar a falar com componentes específicos.
#include <Wire.h> | // Permite a comunicação I2C (usada para

falar com a placa dos servos)
#include <Adafruit_PWMServoDriver.h> // Biblioteca específica para controlar a placa de servos (PCA9685)

// Criar o "objeto" que controla os servos. Imagine isto como contratar um gestor para os motores.
Adafruit_PWMServoDriver pwm = Adafruit_PWMServoDriver();

// --- CALIBRAÇÃO (Ajustes mecânicos) ---

// Estes valores definem os limites físicos dos motores para não partirem o braço.
// Um servo motor move-se com base num sinal de "pulso".
#define SERVOMIN 100 // Valor do pulso para o motor ir para a posição MÍNIMA #define SERVOMAX 500 // Valor do pulso para o motor ir para a posição MÁXIMA

// --- VARIÁVEIS GLOBAIS ---
// Gavetas na memória para guardar números que vamos usar muitas vezes.
int PULSO_ABERTO; // Guardará o valor necessário para ABRIR a mão (90 graus) int PULSO_FECHADO; // Guardará o valor necessário para FECHAR a mão (0 graus)

// --- DEFINIÇÃO DE PINOS / PORTAS (Onde ligamos os cabos) ---
// Placa PCA9685 tem várias portas numeradas de 0 a 15.
// Aqui damos nomes a esses números para ser mais fácil de ler o código.
#define PORTA_COTOVELO 0 | // O motor do cotovelo está ligado na porta 0

#define PORTA_DEDO1 | 13 // Dedo Polegar

#define PORTA_DEDO2 | 11 // Dedo Indicador

#define PORTA_DEDO3 | 10 // Dedo Médio

#define PORTA_DEDO4 | 15 // Dedo Anelar

#define PORTA_DEDO5 | 14 // Dedo Mínimo

#define PORTA_ROTACAO 12 // O motor que roda o pulso

// --- COMUNICAÇÃO (Conversa entre máquinas) ---
// Variáveis para receber texto do Raspberry Pi
char g_bufferPC[100]; | // Uma "frase" pode ter até 100 letras
bool g_mensagemPronta = false; // "Bandeira" que sobe quando uma frase completa chegou
int g_bufferIndex = 0; | // Contador para saber em que letra vamos

/*
*
================================================================================= =====
* FUNÇÃO SETUP (Configuração Inicial)
* Esta função corre apenas UMA VEZ quando ligamos o Arduino.
* Serve para preparar tudo antes de começar a trabalhar.
*
================================================================================= =====
*/
void setup() {
// 1. Iniciar Comunicações (Canais de Rádio)
// Serial: Ligação ao computador (cabo USB) para ver mensagens de erro no ecrã (Debug).
// Serial2: Ligação ao Arduino Uno (que controla a base rotativa).

// Serial3: Ligação ao Raspberry Pi (o cérebro da visão).

Serial.begin(115200); | // Velocidade rápida para o PC
Serial2.begin(9600); | // Velocidade normal para o Arduino Uno
Serial3.begin(115200); // Velocidade rápida para o Raspberry Pi

// 2. Iniciar o Controlador de Servos (PCA9685)
pwm.begin(); | // Acorda a placa de servos
pwm.setPWMFreq(50); | // Define a frequência para 50Hz (padrão para servos
analógicos)
Wire.setClock(400000); // Acelera a comunicação I2C para responder mais depressa

// 3. PRÉ-CÁLCULO DE POSIÇÕES
// A função 'map' traduz graus (0-180) para valores de pulso do motor (100-500).
// Estamos a calcular isto agora para não ter de fazer contas a toda a hora. PULSO_ABERTO = map(0, 0, 180, SERVOMIN, SERVOMAX); // 0 graus = Aberto PULSO_FECHADO = map(180, 0, 180, SERVOMIN, SERVOMAX); // 180 graus = Fechado

delay(10); // Pequena pausa para garantir que tudo estabiliza

// 4. Posição de Início
moverTodos(0); // Manda todos os servos para a posição 0 (repouso)

// Mensagens para o humano ler no ecrã do PC
Serial.println("MEGA PRONTO (MODO TURBO 115200) + ROTACAO + DEBUG ATIVADO"); Serial.println("Mensagens exemplo para debug: "); Serial.println("$1,0,1,1,1,1,1,90");
Serial.println("Aguardando comandos...");
}

/*
*
================================================================================= =====
* FUNÇÃO LOOP (Ciclo Infinito)
* Esta função repete-se para sempre, milhares de vezes por segundo.
* Aqui é onde o Arduino "vive" e trabalha.
*
================================================================================= =====
*/
void loop() {
// --- PARTE 1: ESCUTAR O RASPBERRY PI ---

// Enquanto houver dados a chegar do Pi e a mensagem não estiver terminada... while (Serial3.available() > 0 && !g_mensagemPronta) {
char inChar = Serial3.read(); // Lê uma letra

if (inChar == '$') {
// O símbolo '$' marca o INÍCIO de uma nova mensagem.
// Se virmos isto, reiniciamos o contador para começar a escrever do zero. g_bufferIndex = 0;
}
else if (inChar == '\n') {
// O símbolo '\n' (mudança de linha) marca o FIM da mensagem. g_bufferPC[g_bufferIndex] = '\0'; // Fecha a "string" (texto) corretamente
g_mensagemPronta = true; | // Levanta a bandeira: "Temos uma ordem!"
}
else if (g_bufferIndex < 99) {
// Se não for início nem fim, é conteúdo (ex: '1', ',', '9').
// Guardamos no buffer e avançamos o contador. g_bufferPC[g_bufferIndex] = inChar;
g_bufferIndex++;
}
}

// --- PARTE 2: EXECUTAR A ORDEM ---
// Se a bandeira estiver levantada (mensagem completa recebida)...
if (g_mensagemPronta) {
processarMensagemRapida(); // Chama a função que distribui as tarefas g_mensagemPronta = false; // Baixa a bandeira e prepara para a próxima g_bufferIndex = 0;
}
}

/*
*
================================================================================= =====
* FUNÇÃO: processarMensagemRapida
* Objetivo: Pegar no texto recebido e comandar cada motor individualmente.
* Formato da mensagem esperada: "$orient,flex,d1,d2,d3,d4,d5,rotacao"
*
* Exemplo: "1,0,1,1,1,1,1,90"
* Significa:
* | - Orientação (Base): 1
* | - Flexão (Cotovelo): 0
* | - Dedos (1-5): Todos 1 (fechados/abertos dependendo da lógica)
* | - Rotação: 90 graus

*
================================================================================= =====
*/
void processarMensagemRapida() {
// DEBUG: Mostra no ecrã do PC o que o Arduino acabou de ouvir Serial.print("RX (Recebido): ");
Serial.println(g_bufferPC);

// A função 'strtok' serve para "partir" o texto sempre que encontra uma vírgula.

// --- PASSO 1: BASE (Arduino Uno) ---
// Pega na primeira parte do texto (antes da primeira vírgula) char* token = strtok(g_bufferPC, ",");
if (token == NULL) return; // Se não houver nada, cancela (segurança)

// Envia essa ordem para o outro Arduino (Uno) que controla a base Serial2.write(token[0]);
Serial.print("BASE -> Uno: ");
Serial.println(token[0]);

// --- PASSO 2: SERVOS (Mão e Cotovelo) ---
// Para cada componente, lemos o próximo pedaço do texto e movemos o motor.

// Cotovelo (Digital: 0 ou 1)
moverDigital(PORTA_COTOVELO);

// Dedos (Digital: 0 ou 1) moverDigital(PORTA_DEDO1); // Polegar moverDigital(PORTA_DEDO2); // Indicador moverDigital(PORTA_DEDO3); // Médio moverDigital(PORTA_DEDO4); // Anelar moverDigital(PORTA_DEDO5); // Mínimo

// --- PASSO 3: ROTAÇÃO DO PULSO (Analógico: 0 a 180 graus) ---moverAnalogico(PORTA_ROTACAO);
}

/*
*
================================================================================= =====
* FUNÇÃO: moverDigital
* Objetivo: Controlar motores que só têm dois estados (Aberto/Fechado).

* Argumentos: 'porta' (qual o motor que vamos mexer).
*
================================================================================= =====
*/
inline void moverDigital(int porta) {
// 'strtok(NULL, ",")' pede o PRÓXIMO pedaço de texto após a última vírgula encontrada
char* token = strtok(NULL, ",");

if (token != NULL) {
// Verifica se a ordem é "1" ou "0"
// Sintaxe: (condição) ? valor_se_verdadeiro : valor_se_falso int pulso = (token[0] == '1') ? PULSO_FECHADO : PULSO_ABERTO;

// Manda a ordem para a placa de servos
pwm.setPWM(porta, 0, pulso);

// Mensagem de debug para o técnico ver no PC Serial.print("D["); Serial.print(porta); Serial.print("]: "); Serial.print(token[0] == '0' ? "FECHADO" : "ABERTO"); Serial.print(" ("); Serial.print(pulso); Serial.println(")"); }
}

/*
*
================================================================================= =====
* FUNÇÃO: moverAnalogico
* Objetivo: Controlar motores que podem estar em qualquer ângulo (0-180).
* USADO PARA: Rotação do pulso.
*
================================================================================= =====
*/
inline void moverAnalogico(int porta) {
char* token = strtok(NULL, ",");

if (token != NULL) {
// 'atoi' converte texto ("123") para número inteiro (123)
int angulo = atoi(token);

// SEGURANÇA: Impedir que o motor tente ir além dos limites físicos if (angulo < 0) angulo = 0;

if (angulo > 180) angulo = 180;

// Traduz o ângulo (0-180) para o "idioma" do motor (pulsos) int pulso = map(angulo, 0, 180, SERVOMIN, SERVOMAX);

// Executa o movimento
pwm.setPWM(porta, 0, pulso);

Serial.print("ROT["); Serial.print(porta); Serial.print("]: "); Serial.print(angulo);
Serial.print(" deg ("); Serial.print(pulso); Serial.println(")"); }
}

/*
*
================================================================================= =====
* FUNÇÃO: moverTodos
* Objetivo: Mover todos os motores para um ângulo específico de uma vez.
* Útil para inicialização.
*
================================================================================= =====
*/
void moverTodos(int ang) {
int pulso = map(ang, 0, 180, SERVOMIN, SERVOMAX); // Loop 'for': Repete para cada motor de 0 a 6 for (int i = 0; i <= 6; i++) {
pwm.setPWM(i, 0, pulso);
}
}

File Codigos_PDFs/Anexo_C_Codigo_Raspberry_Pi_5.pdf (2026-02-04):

"""
================================================================================= =====
NOME DO FICHEIRO:
ArmController_PT.py
================================================================================= =====

DESCRIÇÃO PARA PRINCIPIANTES:
Este programa corre num Raspberry Pi 5 (um pequeno computador).
Ele usa uma câmara para ver o movimento do braço e da mão de uma pessoa e traduz esses movimentos para comandos que o robô consegue entender.

O que este programa faz:
1. Captura vídeo da câmara (Raspberry Pi Camera Module 3).
2. Usa "Inteligência Artificial" (MediaPipe) para detetar onde estão os dedos, o cotovelo e o ombro.
3. Faz cálculos matemáticos para perceber se o braço está esticado ou dobrado, e para onde está a apontar.
4. Envia essas informações por comunicação em série (RX/TX) para o Arduino, que controla os motores.

LINGUAGEM: Python
================================================================================= =====
"""

# --- IMPORTAR BIBLIOTECAS (Ferramentas já feitas) ---

import cv2 | # "OpenCV": Ferramenta para processar imagens e vídeo
import mediapipe as mp | # "MediaPipe": A ferramenta da Google que deteta mãos
e corpos
import math | # Ferramentas de matemática (ângulos, distâncias)
import statistics | # Para calcular médias
import time | # Para controlar o tempo (pausas, medir atrasos)
import serial | # Para falar com o Arduino por cabo USB/Série
from picamera2 import Picamera2 # Biblioteca específica para controlar a câmara do Raspberry Pi 5 (Pi Camera Module 3)
import numpy as np | # Ferramenta para cálculos matemáticos avançados

# ------------------ CONFIGURAÇÃO OTIMIZADA PARA O RASPBERRY PI ------------------

# Definimos o tamanho da imagem. Imagens mais pequenas são processadas mais depressa.

FRAME_WIDTH = 640 # Largura em pixels
FRAME_HEIGHT = 480 # Altura em pixels

FPS_TARGET = 30 # Objetivamos 30 imagens por segundo (fluidez normal de vídeo)

# --- CONFIGURAÇÃO DA COMUNICAÇÃO (SERIE) ---

# Aqui dizemos onde o Arduino está ligado e a que velocidade falar com ele. SERIAL_PORT = "/dev/ttyAMA0" # Porta interna do Raspberry Pi (Pinos GPIO)

BAUD_RATE = 115200 | # Velocidade da conversa (bits por segundo). Tem de
ser igual no Arduino!
SEND_INTERVAL = 0.1 | # Só enviamos dados a cada 0.1 segundos (10
vezes/segundo) para não entupir

# ---------- PARÂMETROS AJUSTÁVEIS (Afinações) ----------

# Limiares: São valores de referência. Se passarmos deste valor, considerada-se "Aberto" ou "Fechado".

# Dedos: Ângulo mínimo para considerar o dedo ABERTO.

TH_POLEGAR = 150.0
TH_INDICADOR = 160.0
TH_MEDIO = 150.0
TH_ANELAR = 150.0
TH_MINDINHO = 140.0

# Braço: Ângulos para saber para onde o braço aponta.

TH_BRACO_ESQUERDA = 70 # 0 a 70 graus: Braço virado para o corpo (Esquerda) TH_BRACO_CENTRO_MAX = 130 # 70 a 130 graus: Braço em frente
# 130 a 180 graus: Braço para fora (Direita)

# Flexão: Diferença de altura (Y) entre o pulso e o ombro para saber se o braço está levantado.

TH_FLEXAO_Y = 0.1 # Se a diferença for maior que 0.1, consideramos "Fletido" # ---------------------------------------------------------------

# --- INICIALIZAR O MEDIAPIPE (A Inteligência Artificial) ---

mp_pose = mp.solutions.pose | # Módulo para detetar corpo (ombros, cotovelos)
mp_hands = mp.solutions.hands | # Módulo para detetar mãos/dedos
mp_drawing = mp.solutions.drawing_utils # Útil para desenhar os "esqueletos" no ecrã

# Configuração visual das linhas que vamos desenhar no ecrã

drawing_spec_thin = mp_drawing.DrawingSpec(thickness=1, circle_radius=1) drawing_spec_conn = mp_drawing.DrawingSpec(thickness=1)

# Definição dos Dedos: Dicionário que diz quais os pontos (landmarks) formam cada dedo

FINGERS = {

"polegar": [1, 2, 4], # Pontos específicos da mão que formam o polegar "indicador": [5, 6, 8],
"medio": [9, 10, 12],
"anelar": [13, 14, 16],
"mindinho": [17, 18, 20]
}

# Associação dos limiares a cada dedo FINGER_THRESHOLDS = {

"polegar": TH_POLEGAR,
"indicador": TH_INDICADOR, "medio": TH_MEDIO,
"anelar": TH_ANELAR,
"mindinho": TH_MINDINHO
}

# -------- INICIAR LIGAÇÃO AO ARDUINO --------

try:
arduino = serial.Serial(SERIAL_PORT, BAUD_RATE, timeout=1) time.sleep(2) # Esperar 2 segundos para o Arduino acordar bem print(f"Ligado ao Arduino em {SERIAL_PORT}")
except Exception as e:
# Se falhar (cabo desligado?), avisa mas não para o programa print(f"Não foi possível ligar ao Arduino: {e}")

print(f" Verifica a porta. Podes usar: ls /dev/tty*") arduino = None

# -------- FUNÇÕES DE LÓGICA (O Cérebro do Programa) --------

def angulo_3pts(a, b, c):
"""
Calcula o ângulo entre 3 pontos (como um cotovelo: ombro, cotovelo, pulso). Recebe: Pontos a, b, c (coordenadas x,y).
Devolve: Ângulo em graus.
"""
# Matemática vetorial (cálculo de diferenças e produtos internos)

# Não precisas de perceber a matemática complexa aqui, basta saber que devolve um ângulo.

ax, ay = a[0]-b[0], a[1]-b[1]
cx, cy = c[0]-b[0], c[1]-b[1]
num = ax*cx + ay*cy
den = math.hypot(ax, ay) * math.hypot(cx, cy) + 1e-8 cosv = max(-1.0, min(1.0, num/den))
ang = math.degrees(math.acos(cosv))
return ang def finger_angle_open(hand_landmarks, ids):
"""
Vê se um dedo está esticado ou dobrado. Mede o ângulo na 'dobradiça' do meio do dedo. """
a = hand_landmarks.landmark[ids[0]]
b = hand_landmarks.landmark[ids[1]]
c = hand_landmarks.landmark[ids[2]]
return angulo_3pts((a.x,a.y),(b.x,b.y),(c.x,c.y))

def hand_center(hand_landmarks):
"""Calcula o ponto central da mão (média de todos os pontos).""" xs = [lm.x for lm in hand_landmarks.landmark]
ys = [lm.y for lm in hand_landmarks.landmark]
return (statistics.mean(xs), statistics.mean(ys))

def pair_hand_to_pose_side(hand_cx, hand_cy, pose_landmarks):
"""
Descobre se a mão que estamos a ver é a DIREITA ou a ESQUERDA.
Como faz? Vê qual dos pulsos do corpo (detetado pelo Pose) está mais perto da mão.
"""
if pose_landmarks is None:
return None
lw = pose_landmarks.landmark[15] # Pulso esquerdo do corpo rw = pose_landmarks.landmark[16] # Pulso direito do corpo

# Calcular distância (Teorema de Pitágoras)

dl = math.hypot(hand_cx - lw.x, hand_cy - lw.y)
dr = math.hypot(hand_cx - rw.x, hand_cy - rw.y)

return "Left" if dl < dr else "Right" # Retorna "Left" (Esq) ou "Right" (Dir)

def determinar_orientacion_brazo(angulo):
"""Diz para onde o braço está a apontar com base no ângulo do ombro."""
if angulo <= TH_BRACO_ESQUERDA:
return "Esquerda (para o corpo)"
elif angulo <= TH_BRACO_CENTRO_MAX:
return "Centro (frente)"
else:
return "Direita (para fora)"

def determinar_flexion_brazo(hombro_y, muneca_y): """

Diz se o braço está levantado (fletido). Compara a altura (Y) do ombro e do pulso. """
diff_y = abs(hombro_y - muneca_y)
if diff_y > TH_FLEXAO_Y:
return "Fletido", diff_y
else:
return "Estendido", diff_y

def calculate_hand_rotation(hand_landmarks, flex_status, arm_orientation):
"""
A função mais complexa: Tenta adivinhar se a palma da mão está virada para a câmara ou de costas.
Usa a posição do Polegar (Thumb) e do Mindinho (Pinky).

Devolve um valor entre -1.0 (Palma para a câmara) e 1.0 (Costas da mão / Dorso).
"""
thumb = hand_landmarks.landmark[4] # Ponto na ponta do polegar
pinky = hand_landmarks.landmark[20] # Ponto na ponta do mindinho

diff = 0
t_val = 0
p_val = 0
axis_used = "Indef"

# Dependendo se o braço está fletido ou esticado, a lógica muda (porque a mão roda anatomicamente).

is_flexed = (flex_status == "Fletido")

if is_flexed:
# CASO 1: Braço Fletido (Dobrado)

# Usamos a diferença no eixo X (Horizontal) t_val = thumb.x

p_val = pinky.x
diff = -(t_val - p_val)
axis_used = "X (Fletido)"

else:
# Braço Estendido

if "Direita" in arm_orientation:
# CASO 3: Esticado para a Direita -> Usamos eixo Y (Vertical) t_val = thumb.y

p_val = pinky.y
diff = (t_val - p_val)

axis_used = "Y (Ext-Dir)"

else:
# CASO 2: Esticado para o Centro/Corpo -> Usamos eixo Y Invertido t_val = thumb.y

p_val = pinky.y
diff = -(t_val - p_val)
axis_used = "Y-Inv (Ext-Corpo)"

# Normalização: Converte a diferença bruta em pixels num valor padrão entre -1 e 1

MAX_DIFF = 0.22
rotation_value = max(-1.0, min(1.0, diff / MAX_DIFF))

# Classificar por texto para ajudar no Debug orientation = "Indefinido"

if rotation_value < -0.3:
orientation = "Palma (Camara)"
elif rotation_value > 0.3: orientation = "Dorso (Camara)" else:
orientation = "A rodar / Canto"

return diff, rotation_value, orientation, axis_used

# -------- INICIALIZAÇÃO DO LOOP (CICLO) DA CÂMARA E MODELOS --------

# 1. Configurar e ligar a câmara

print("A inicializar Picamera2...")
picam2 = Picamera2()
config = picam2.create_preview_configuration(
main={"size": (FRAME_WIDTH, FRAME_HEIGHT), "format": "RGB888"}, controls={"FrameRate": FPS_TARGET}
)
picam2.configure(config)
picam2.start()

print("Câmara iniciada. A aguardar estabilização...") time.sleep(2)

# 2. Configurar os modelos de deteção (MediaPipe) pose = mp_pose.Pose(

min_detection_confidence=0.5, min_tracking_confidence=0.5, model_complexity=1

)
hands = mp_hands.Hands(
max_num_hands=2,
min_detection_confidence=0.5, min_tracking_confidence=0.5, model_complexity=1
)

# Variáveis de controlo

frame_count = 0 | # Conta quantos frames já passaram
start_time = time.time() | # Guarda a hora de início
last_send = time.time() | # Guarda a hora do último envio para o Arduino

print("Sistema iniciado. Pressiona Ctrl+C para sair.")

try:
# --- CICLO INFINITO (Repete para cada imagem da câmara) ---while True:

# 1. Capturar imagem

frame = picam2.capture_array()

# 2. Processar com Inteligência Artificial pose_res = pose.process(frame) # Procura corpo hands_res = hands.process(frame) # Procura mãos

# Cria uma cópia da imagem para desenhar por cima (out) out = frame

h, w = frame.shape[:2]

# Preparar variáveis vazias (reset) ang_brazo = None

orientacion_brazo = "Indefinido" estado_flexion = "Estendido"
side = None
hombro_y = 0
muneca_y = 0
diff_y = 0

hand_rotation_val = 0
hand_orientation_str = ""

# --- PARTE A: ANÁLISE DO CORPO (POSE) ---if pose_res.pose_landmarks:

plm = pose_res.pose_landmarks.landmark

# Tenta descobrir qual é o braço ativo usando a mão detetada if hands_res.multi_hand_landmarks:

hand_lm_check = hands_res.multi_hand_landmarks[0] hc_x, hc_y = hand_center(hand_lm_check)
side = pair_hand_to_pose_side(hc_x, hc_y, pose_res.pose_landmarks)

# Se não tiver a certeza, assume direita

if side is None:
side = "Right"

# Seleciona os pontos certos (Ombro, Cotovelo, Pulso) dependendo do lado

if side == "Left": # Pontos 11, 13, 15 são do lado esquerdo
sh = plm[11]; el = plm[13]; wr = plm[15]
else: | # Pontos 12, 14, 16 são do lado direito
sh = plm[12]; el = plm[14]; wr = plm[16]

# Calcula ângulos e lógica

ang_brazo = angulo_3pts((sh.x, sh.y), (el.x, el.y), (wr.x, wr.y)) orientacion_brazo = determinar_orientacion_brazo(ang_brazo) hombro_y = sh.y; muneca_y = wr.y
estado_flexion, diff_y = determinar_flexion_brazo(hombro_y, muneca_y)

# Escreve textos no ecrã para vermos o que ele está a pensar cv2.putText(out, f"Braco ({side}): {int(ang_brazo)} deg",

| (10, 30), cv2.FONT_HERSHEY_SIMPLEX, 0.6, (0, 255, 0), 1)
cv2.putText(out, f"Orient: {orientacion_brazo}",
| (10, 50), cv2.FONT_HERSHEY_SIMPLEX, 0.6, (0, 255, 255),
1)
cv2.putText(out, f"Flex: {estado_flexion}",
| (10, 70), cv2.FONT_HERSHEY_SIMPLEX, 0.6, (255, 150, 0),
1)

# Desenha o esqueleto no ecrã mp_drawing.draw_landmarks(out, pose_res.pose_landmarks, mp_pose.POSE_CONNECTIONS,

| drawing_spec_thin, drawing_spec_conn)

# --- PARTE B: ANÁLISE DA MÃO ---estados_dedos = {}

found_hand = False

if hands_res.multi_hand_landmarks: found_hand = True hand_lm = hands_res.multi_hand_landmarks[0] # Usa a primeira mão encontrada

# Calcular Rotação da mão (Palma/Dorso)

_, hand_rotation_val, hand_orientation_str, _ = calculate_hand_rotation(
hand_lm, estado_flexion, orientacion_brazo)

# Calcular se cada dedo está aberto ou fechado for name, ids in FINGERS.items():

ang = finger_angle_open(hand_lm, ids)
umbral = FINGER_THRESHOLDS[name]
abierto = ang > umbral # Verdadeiro se Ângulo > Limite estados_dedos[name] = (abierto, ang)

# --- DESENHOS DE DEBUG (Ajuda visual) ---

# Barra de rotação

bar_x, bar_y, bar_w, bar_h = 300, 30, 150, 15
cv2.rectangle(out, (bar_x, bar_y), (bar_x + bar_w, bar_y + bar_h), (100, 100, 100), 2)
norm_pos = int((hand_rotation_val + 1) / 2 * bar_w) # Posicionar o ponto na barra
cv2.circle(out, (bar_x + norm_pos, bar_y + int(bar_h/2)), 6, (0, 255, 255), -1)
cv2.putText(out, f"Rot: {hand_rotation_val:.2f}", (bar_x, bar_y-5), cv2.FONT_HERSHEY_SIMPLEX, 0.5, (0, 255, 255), 1)

# Lista dos dedos no canto do ecrã

y0 = 100
ordered_keys = ["indicador", "medio", "anelar", "mindinho", "polegar"]
for i, k in enumerate(ordered_keys):
abierto, ang = estados_dedos[k]
color = (0, 255, 0) if abierto else (0, 0, 255) # Verde se aberto, Vermelho se fechado cv2.putText(out, f"{k}: {int(ang)}", (10, y0 + i*20), cv2.FONT_HERSHEY_SIMPLEX, 0.5, color, 1)

# Desenha os elos da mão

mp_drawing.draw_landmarks(out, hand_lm, mp_hands.HAND_CONNECTIONS, drawing_spec_thin, drawing_spec_conn)

# --- PARTE C: ENVIAR COMANDOS PARA O ARDUINO ---

# Só envia se passou tempo suficiente (SEND_INTERVAL) e se temos o Arduino ligado

if time.time() - last_send > SEND_INTERVAL and arduino and found_hand:

# 1. Converter Base/Ombro para números (0, 1, 2)

val_orient = 1 # Centro (Padrão)
if "Esquerda" in orientacion_brazo: val_orient = 0 elif "Direita" in orientacion_brazo: val_orient = 2

# 2. Converter Flexão para número (0 ou 1) val_flex = 1 if estado_flexion == "Fletido" else 0

# 3. Converter lista de dedos para 0s e 1s

d_list = []
ordered_keys = ["indicador", "medio", "anelar", "mindinho", "polegar"]
for k in ordered_keys:
if k in estados_dedos:
d_list.append(1 if estados_dedos[k][0] else 0) else:
d_list.append(0)

# 4. Converter rotação (-1.0 a 1.0) para graus (0 a 180) para o servo rot_deg = int((hand_rotation_val + 1.0) * 90)

rot_deg = max(0, min(180, rot_deg)) # Forçar limites entre 0 e 180

# 5. Criar a mensagem de texto

# Formato: "$orient,flex,d1,d2,d3,d4,d5,rot\n"

dedos_str = ",".join(map(str, d_list))
msg = f"${val_orient},{val_flex},{dedos_str},{rot_deg}\n"

try:
arduino.write(msg.encode()) # Enviar pelo cabo
last_send = time.time()
# print(f"TX: {msg.strip()}") # (Opcional: Ver o que enviámos) except Exception as e:

print(f"Erro na Série: {e}")

# --- PARTE D: MOSTRAR IMAGEM ---

cv2.imshow("RPi Hand Tracking", out)

# Se carregar na tecla ESC (código 27), sair do programa if cv2.waitKey(1) & 0xFF == 27:

break

# --- ESTATÍSTICAS (FPS) ---frame_count += 1

if frame_count % 30 == 0:
elapsed = time.time() - start_time
# Imprime na consola a velocidade (FPS) e rotação atual

print(f"FPS: {frame_count/elapsed:.1f} | Rot:
{hand_rotation_val:.2f}")

except KeyboardInterrupt:
print("\nA parar (Ctrl+C pressionado)...")

finally:
# Limpeza final: Desligar câmara, fechar janelas e ligação Arduino picam2.stop()

if arduino:
arduino.close()
cv2.destroyAllWindows()
print("Fim.")

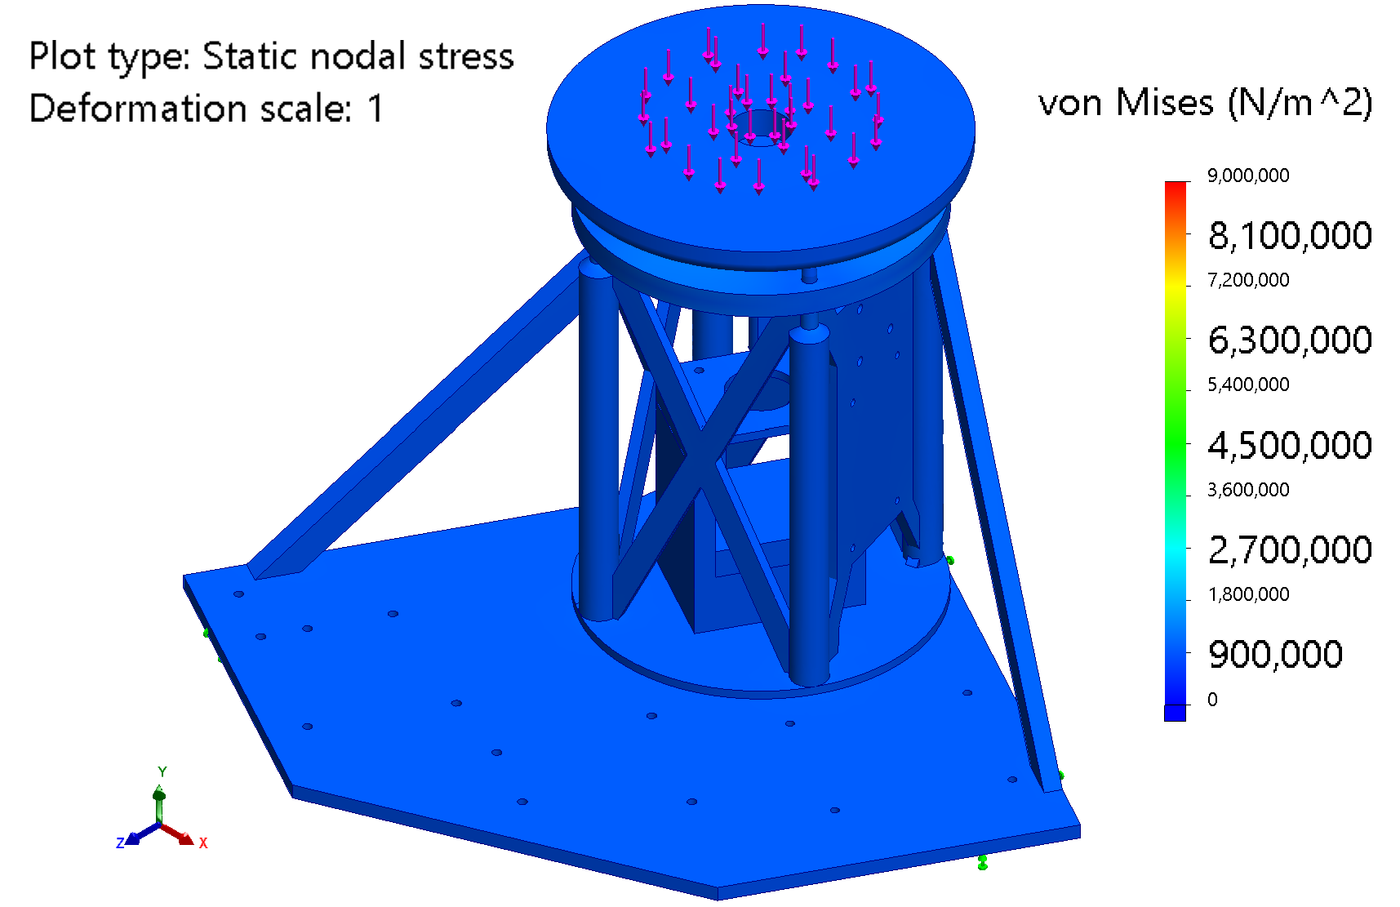
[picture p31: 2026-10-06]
media/robArm_img/stress2_big.png

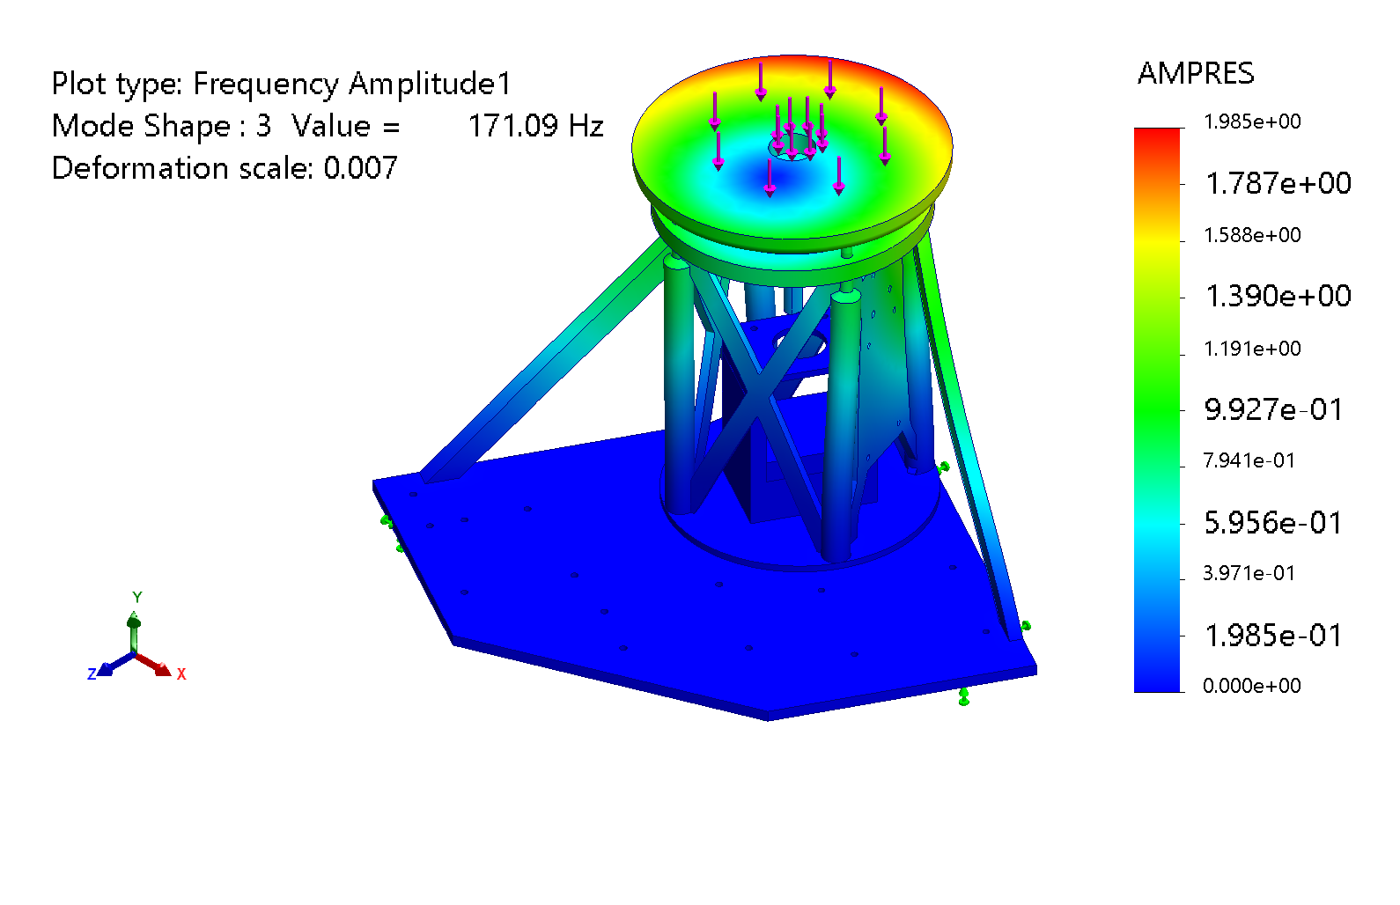
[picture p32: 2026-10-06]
media/robArm_img/thirdHarmonic2_big.png

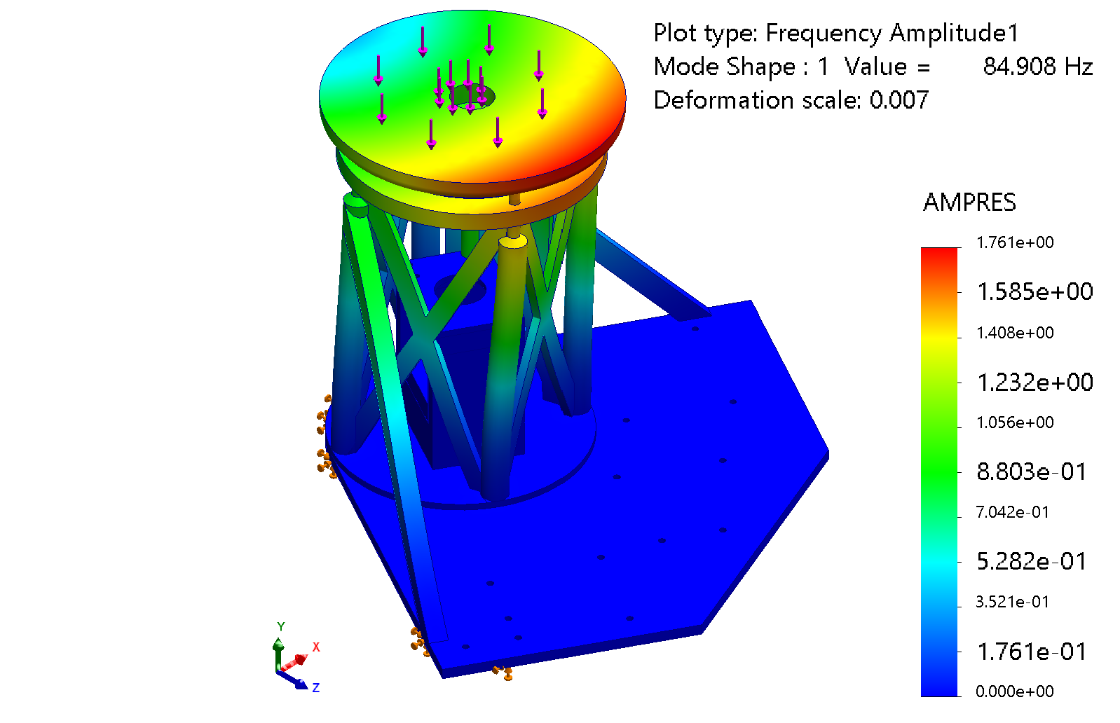
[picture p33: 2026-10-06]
media/robArm_img/fundamental Frequency2_big.png

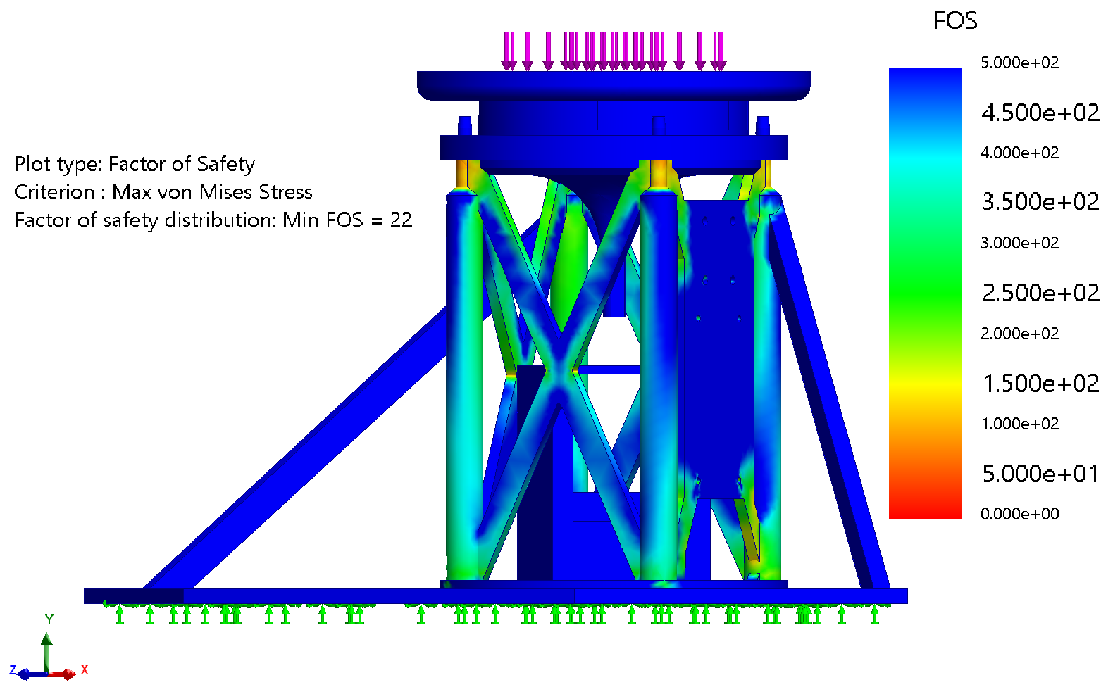
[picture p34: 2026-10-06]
media/robArm_img/FOS2_big.png

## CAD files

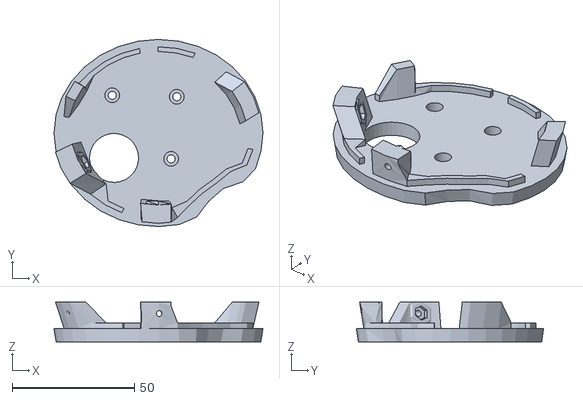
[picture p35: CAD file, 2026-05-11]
Custom_Base_STL/Peca_Inmoov_ASS_2.STL
85.5 x 76.5 x 16.2

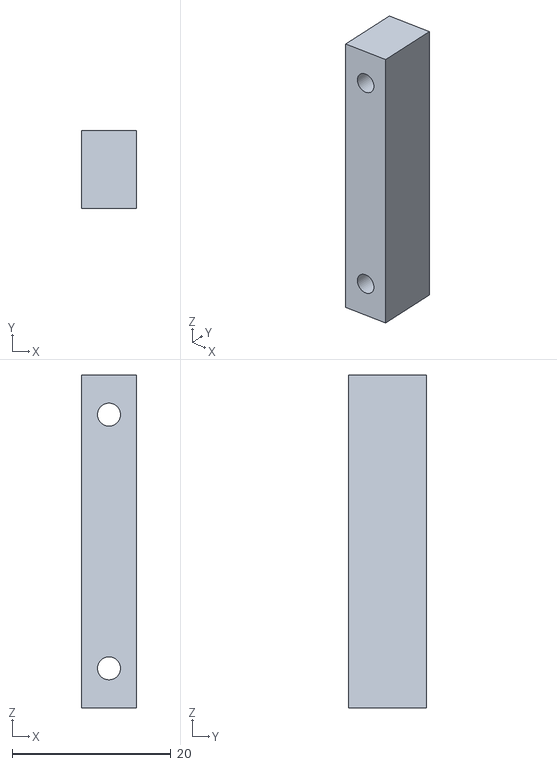
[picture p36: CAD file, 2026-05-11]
Custom_Base_STL/Alongamento.STL
7.00 x 9.80 x 42.0

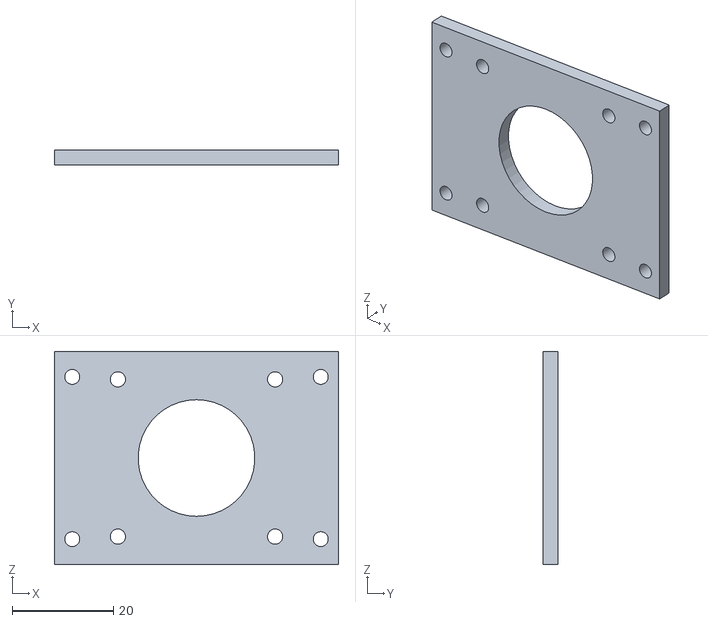
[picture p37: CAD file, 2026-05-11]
Custom_Base_STL/Peca_Prender_Motor.STL
56.0 x 3.00 x 42.0

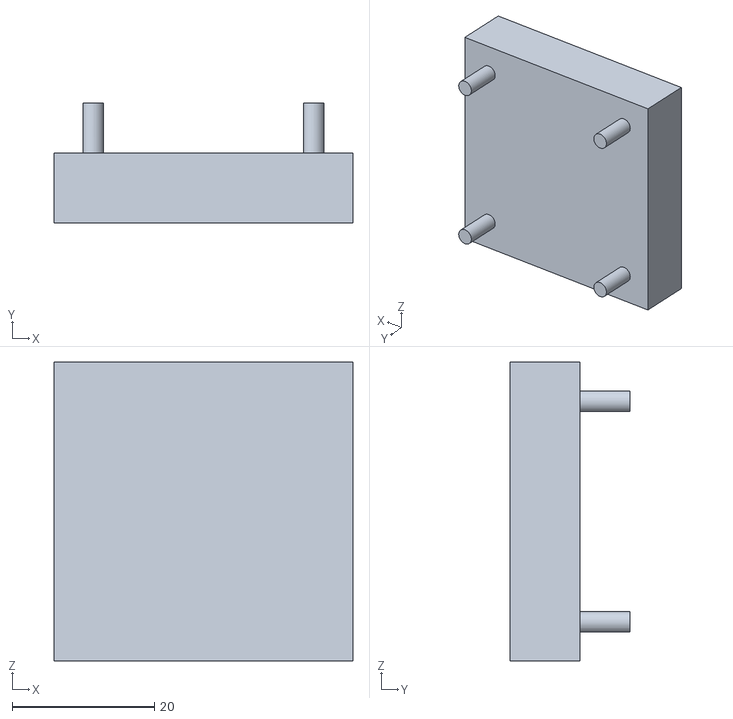
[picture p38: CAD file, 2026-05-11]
Custom_Base_STL/peca_UP.STL
42.0 x 16.8 x 42.0

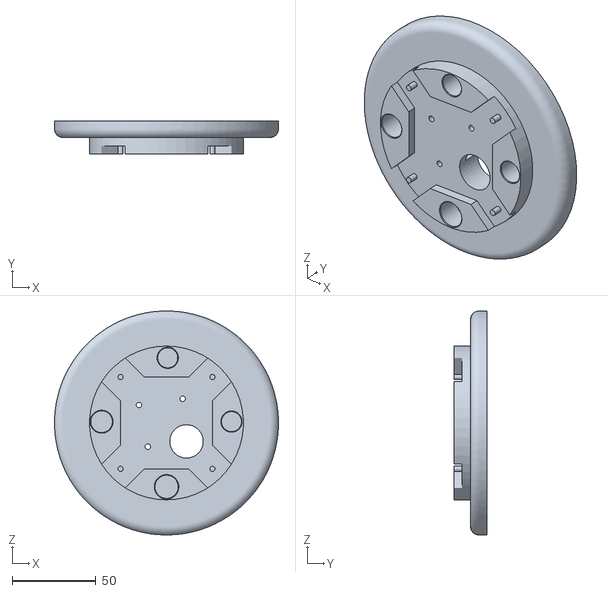
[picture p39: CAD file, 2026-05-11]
Custom_Base_STL/Base_Braco_SUP_ASS_2.STL
134.0 x 20.0 x 134.0

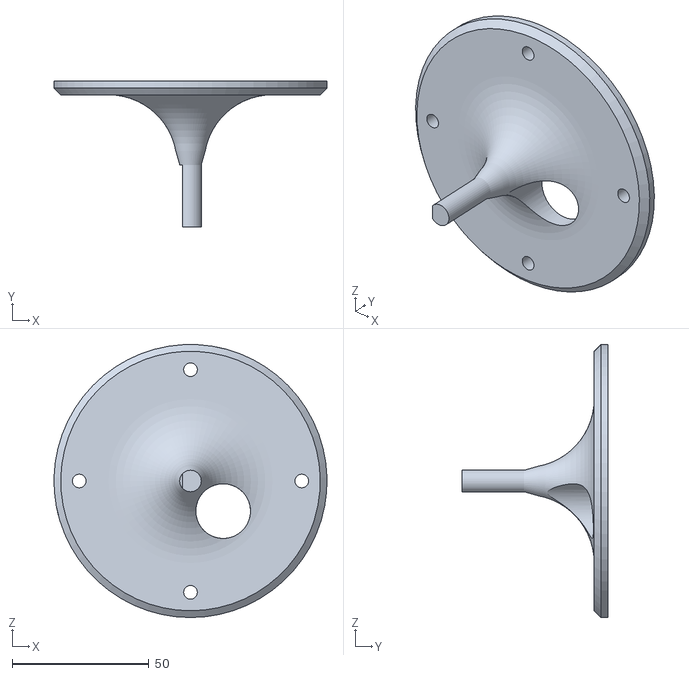
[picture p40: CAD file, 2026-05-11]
Custom_Base_STL/Suporte_Rotativo_ASS_2.STL
100.0 x 53.3 x 100.0

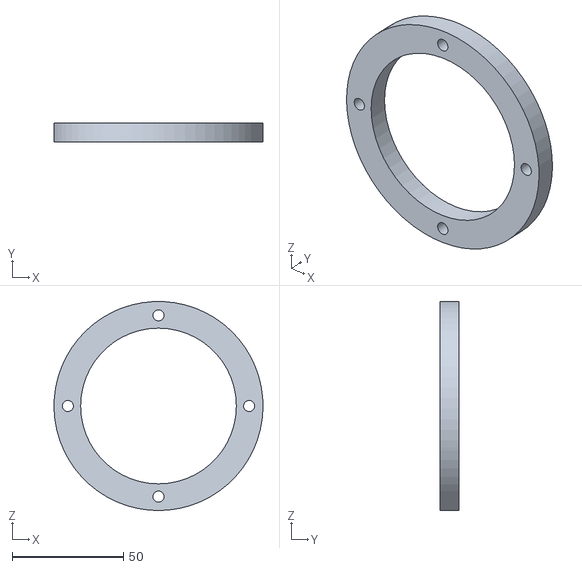
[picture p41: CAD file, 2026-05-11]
Custom_Base_STL/Rolamento_Pequeno.STL
94.0 x 8.40 x 94.0

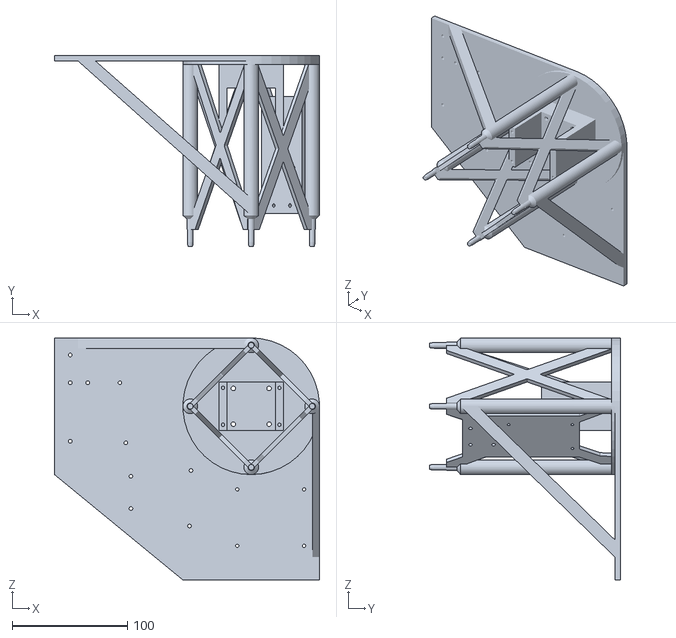
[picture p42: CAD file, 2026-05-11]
Custom_Base_STL/Bottom_Piece.STL
230.0 x 166.0 x 210.0

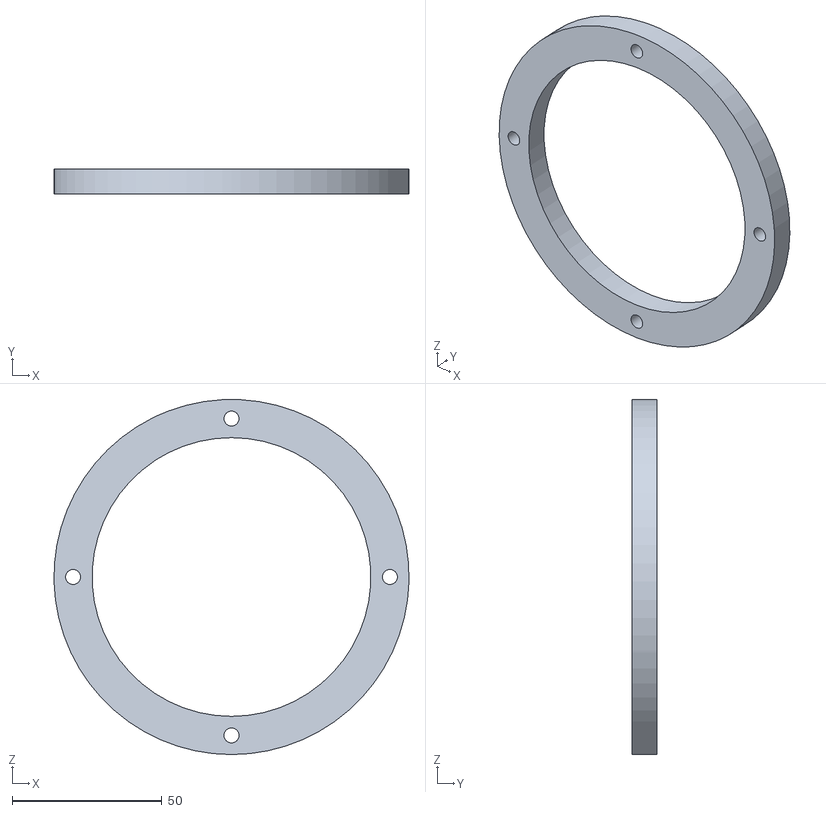
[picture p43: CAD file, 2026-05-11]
Custom_Base_STL/Rolamento_Grande.STL
118.5 x 8.40 x 118.5

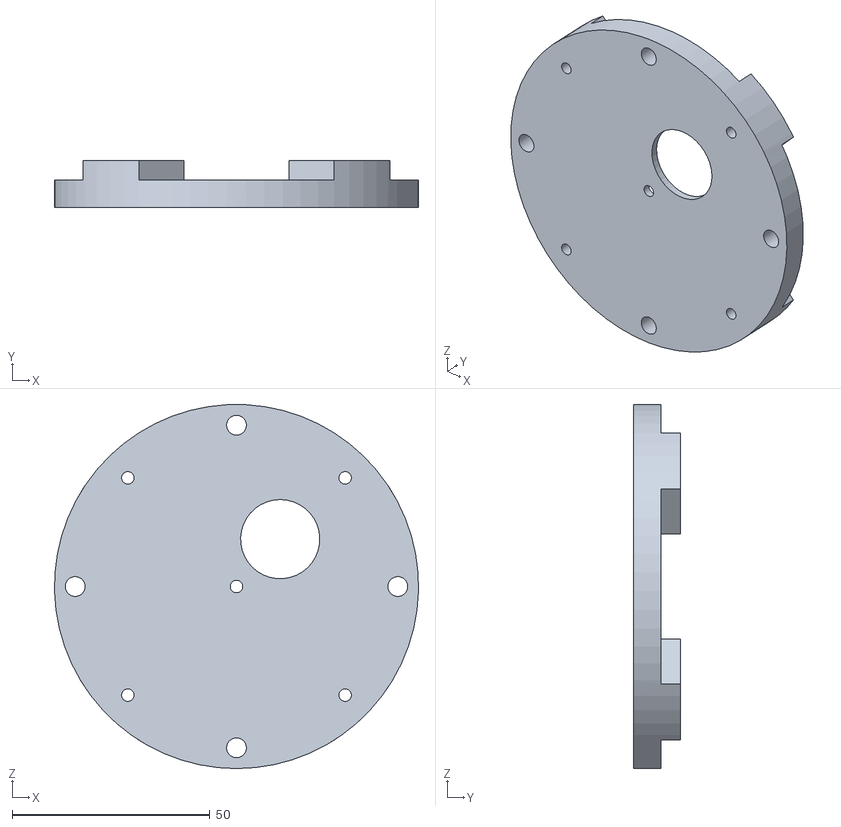
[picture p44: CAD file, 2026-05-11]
Custom_Base_STL/Base_Braco_ASS_2.STL
92.0 x 12.0 x 92.0

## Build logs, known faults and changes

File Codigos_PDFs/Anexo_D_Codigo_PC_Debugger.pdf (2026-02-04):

"""
================================================================================= =====
NOME DO FICHEIRO:
VisionDebugger_PC_PT.py
================================================================================= =====

DESCRIÇÃO:
Este programa é uma versão para executar no Computador (PC).
Serve para testar a "visão" (inteligência artificial) sem precisar do braço ligado.
Usa a webcam do computador para ver a mão e o braço e mostra no ecrã o que está a perceber.

O que este programa faz:
1. Liga a webcam do computador.
2. Usa o MediaPipe (Nova API 'Tasks') para detetar o esqueleto do braço e da mão.
3. Calcula se o braço está fletido, para onde aponta, e se a mão está rodada.
4. Mostra tudo num vídeo no ecrã com desenhos coloridos.
5. Escreve os dados na janela preta (consola) para análise técnica.

Versão FINAL OTIMIZADA.
- Usa "Thread" de vídeo para eliminar atrasos (Lag/Delay).
- Resolução ajustada para 640x480 (Padrão para alta velocidade).
- GPU ativada (Usa a placa gráfica para ser mais rápido).
- Modelo Lite (Versão leve da inteligência artificial).

LINGUAGEM: Python
================================================================================= =====
"""

# --- BIBLIOTECAS (Ferramentas que o programa usa) ---

import cv2 | # "OpenCV": Controla a câmara e janelas de vídeo
import mediapipe as mp | # "MediaPipe": A Inteligência Artificial que deteta
pessoas
import math | # Matemática (cálculo de ângulos)
import statistics | # Estatística (médias)
import time | # Relógio (para medir o tempo e calcular FPS)
import os | # Sistema Operativo (para encontrar ficheiros no PC)
import threading | # "Multitarefa": Permite ler a câmara e processar ao
mesmo tempo

# --- NOVA API MEDIAPIPE TASKS ---

from mediapipe.tasks import python
from mediapipe.tasks.python import vision
================================================================================= =====
# | >>> ÁREA DE CONFIGURAÇÃO (MEXER AQUI) <<<

================================================================================= =====

# 1. CÂMARA (Webcam)

INDICE_CAMERA = 1 | # Qual câmara usar? (0 = Principal, 1 =
Secundária/Externa)
LARGURA_CAMERA = 1280 # Largura da imagem (Recomendado: 640 para rapidez, 1280 para qualidade)
ALTURA_CAMERA = 720 | # Altura da imagem (Recomendado: 480 para rapidez, 720
para qualidade)

# 2. LIMIARES DOS DEDOS (Ângulo mínimo para considerar "Aberto")

# Se o ângulo do dedo for maior que isto, o programa diz "ABERTO" TH_POLEGAR = 150.0

TH_INDICADOR = 160.0
TH_MEDIO = 150.0
TH_ANELAR = 150.0
TH_MINDINHO = 140.0

# 3. LIMIARES DO BRAÇO

TH_BRACO_ESQUERDA = 70 # Graus para considerar virado à esquerda TH_BRACO_CENTRO_MAX = 130 # Até quantos graus é centro?
TH_FLEXAO_Y = 0.1 | # Quão levantado o braço precisa estar para ser
"fletido"

# 4. MAPA DOS DEDOS (Pontos do MediaPipe)

# Diz ao programa quais os "pontos" do esqueleto que formam cada dedo DEDOS = {

"polegar": [1, 2, 4],
"indicador": [5, 6, 8],
"medio": [9, 10, 12],
"anelar": [13, 14, 16],
"mindinho": [17, 18, 20]
}

================================================================================= =====
# | >>> FIM DA CONFIGURAÇÃO <<<

================================================================================= =====

# --- CONSTANTES INTERNAS (Valores fixos que o programa usa) ---

LIMIARES_DEDOS = {
"polegar": TH_POLEGAR,
"indicador": TH_INDICADOR,
"medio": TH_MEDIO,
"anelar": TH_ANELAR,
"mindinho": TH_MINDINHO
}

# Cores para os desenhos (Formato BGR: Azul, Verde, Vermelho)

COR_OSSO_POSE = (0, 255, 0) | # Verde
COR_ARTICULACAO_POSE = (0, 0, 255) # Vermelho
COR_OSSO_MAO = (255, 255, 0) | # Ciano (Amarelo+Verde ?)
COR_ARTICULACAO_MAO = (255, 0, 0) | # Azul
ESPESSURA_LINHAS = 2 | # Espessura da linha para os desenhos
ESPESSURA_PONTOS = 6 | # Espessura dos pontos

# --- CONFIGURAÇÃO DOS MODELOS (Onde estão os ficheiros da IA) ---

# O programa procura os ficheiros ".task" na mesma pasta onde este ficheiro .py está

diretorio_script = os.path.dirname(os.path.abspath(__file__)) CAMINHO_MODELO_POSE = os.path.join(diretorio_script, 'pose_landmarker_lite.task') # 'pose_landmarker_heavy.task' para melhor performance
CAMINHO_MODELO_MAO = os.path.join(diretorio_script, 'hand_landmarker.task')

# --- DEFINIÇÃO DE CLASSES (Ferramentas personalizadas) ---

class FluxoCamera:
"""
CLASSE ESPECIAL: LEITOR DE CÂMARA RÁPIDO
Esta ferramenta lê a câmara numa 'linha separada' (Thread). Isto serve para que o programa nunca fique à espera da câmara. Elimina o 'Lag' ou 'Delay' da imagem.
"""
def __init__(self, src=0, width=640, height=480):
# Inicia a ligação à câmara

self.stream = cv2.VideoCapture(src)

self.stream.set(cv2.CAP_PROP_FRAME_WIDTH, width) self.stream.set(cv2.CAP_PROP_FRAME_HEIGHT, height)
# Tenta dizer ao Windows para não guardar imagens velhas em memória self.stream.set(cv2.CAP_PROP_BUFFERSIZE, 1)

# Lê a primeira imagem

(self.capturado, self.quadro) = self.stream.read() self.parado = False

def iniciar(self):
# Inicia a tarefa em segundo plano (background) threading.Thread(target=self.atualizar, args=()).start() return self

def atualizar(self):
# Loop infinito que só faz uma coisa: Ler a imagem mais recente while True:

if self.parado:
return
(self.capturado, self.quadro) = self.stream.read()

def ler(self):
# Devolve a última imagem capturada

return self.quadro

def parar(self):
# Pára a câmara

self.parado = True
self.stream.release()

# --- FUNÇÕES AUXILIARES (Pequenos comandos úteis) ---

def desenhar_marcos_personalizado(imagem, marcos, conexoes, cor_articulacao, cor_osso):
"""
Função para desenhar o esqueleto (bolinhas e riscos) na imagem.
"""
h, w, _ = imagem.shape # Altura e Largura da imagem
# Desenhar Pontos (Bolinhas)

for mc in marcos:
cx, cy = int(mc.x * w), int(mc.y * h)
cv2.circle(imagem, (cx, cy), ESPESSURA_PONTOS, cor_articulacao, -1) # Desenhar Conexões (Riscos)
if conexoes:
for s, e in conexoes:

if s < len(marcos) and e < len(marcos):
cv2.line(imagem, (int(marcos[s].x*w), int(marcos[s].y*h)), (int(marcos[e].x*w), int(marcos[e].y*h)), cor_osso, ESPESSURA_LINHAS)

def calcular_angulo_3pts(a, b, c):
"""
Matemática: Calcula o ângulo entre 3 pontos.
(Exemplo: Ombro -> Cotovelo -> Pulso para saber se o braço está esticado) """
ax, ay = a[0]-b[0], a[1]-b[1]
cx, cy = c[0]-b[0], c[1]-b[1]
num = ax*cx + ay*cy
den = math.hypot(ax, ay) * math.hypot(cx, cy) + 1e-8 return math.degrees(math.acos(max(-1.0, min(1.0, num/den))))

def calcular_angulo_dedo(lista_marcos_mao, ids):
"""Verifica quanto um dedo está dobrado."""
a = lista_marcos_mao[ids[0]]
b = lista_marcos_mao[ids[1]]
c = lista_marcos_mao[ids[2]]
return calcular_angulo_3pts((a.x,a.y),(b.x,b.y),(c.x,c.y))

def obter_centro_mao(lista_mc):
"""Encontra o centro da mão (média de todos os pontos)."""
return (statistics.mean([l.x for l in lista_mc]), statistics.mean([l.y for l in lista_mc]))

def determinar_lado_mao(cm_x, cm_y, marcos_pose):
"""
Tenta adivinhar se a mão é Esquerda ou Direita.
Compara a distância da mão aos pulsos do corpo.
"""
return "Esquerda" if math.hypot(cm_x - marcos_pose[15].x, cm_y -marcos_pose[15].y) < math.hypot(cm_x - marcos_pose[16].x, cm_y -marcos_pose[16].y) else "Direita"

def determinar_orientacao_braco(angulo):
"""Diz para onde o braço aponta baseado no ângulo do ombro.""" if angulo <= TH_BRACO_ESQUERDA:
return "Esquerda (Corpo)"
elif angulo <= TH_BRACO_CENTRO_MAX:
return "Centro (Frente)"
else:
return "Direita (Fora)"

def determinar_flexao_braco(ombro_y, pulso_y): """
Diz se o braço está levantado (fletido). Compara a altura (Y) do ombro e do pulso. """
diferenca_y = abs(ombro_y - pulso_y)
if diferenca_y > TH_FLEXAO_Y:
return "Fletido", diferenca_y else:
return "Estendido", diferenca_y

def calcular_rotacao_mao(marcos_mao, status_flexao, orientacao_braco, lado="Direita"):
"""
Calcula se a mão está de Palma ou de Costas (Dorso).
Mede a distância entre o Polegar e o Mindinho.
Se a distância for positiva é palma, negativa é dorso (ou vice-versa). """
polegar = marcos_mao[4] # Ponto na ponta do polegar
mindinho = marcos_mao[20] # Ponto na ponta do mindinho

diferenca = 0

# A lógica muda dependendo se o braço está dobrado ou esticado. esta_fletido = (status_flexao == "Fletido")

if esta_fletido:
# CASO 1: Braço Fletido (Dobrado)

# Usamos diferença no eixo X (Horizontal) val_p = polegar.x

val_m = mindinho.x

# LÓGICA CORRETA PARA IMAGEM ESPELHADA (Modo Selfie):

if lado == "Direita":
# Mão Direita (no ecrã Direita): Palma significa Polegar(Esq) < Mindinho(Dir) -> Diferença é Negativa diferenca = -(val_p - val_m)

else:
# Mão Esquerda (no ecrã Esquerda): Palma significa Polegar(Dir) > Mindinho(Esq) -> Diferença é Positiva -> Inverter diferenca = (val_p - val_m)

eixo_usado = "X (Fletido)"

else:

# Braço Estendido

if "Direita" in orientacao_braco:
# CASO 3: Estendido para Direita -> Usar eixo Y (Vertical) val_p = polegar.y

val_m = mindinho.y
diferenca = (val_p - val_m)
eixo_usado = "Y (Est-Dir)"

else:
# CASO 2: Estendido para Centro/Corpo -> Usar eixo Y Invertido val_p = polegar.y

val_m = mindinho.y
diferenca = -(val_p - val_m)
eixo_usado = "Y-Inv (Est-Corpo)"

# Normalização: Converte a diferença bruta de pixels num valor padrão entre -1 e 1

DIF_MAXIMA = 0.22
valor_rotacao = max(-1.0, min(1.0, diferenca / DIF_MAXIMA))

# Classificar por texto para Depuração (Debugging) orientacao = "Indefinido"

if valor_rotacao < -0.3:
orientacao = "Palma"
elif valor_rotacao > 0.3:
orientacao = "Dorso"
else:
orientacao = "A Rodar / Canto"

return diferenca, valor_rotacao, orientacao, eixo_usado

# --- INICIALIZAÇÃO DE MODELOS E CÂMARA (Preparar tudo antes de começar) ---

# 1. Carregar a Inteligência Artificial (MediaPipe)

BaseOptions = mp.tasks.BaseOptions
PoseLandmarker, PoseLandmarkerOptions = mp.tasks.vision.PoseLandmarker, mp.tasks.vision.PoseLandmarkerOptions
HandLandmarker, HandLandmarkerOptions = mp.tasks.vision.HandLandmarker, mp.tasks.vision.HandLandmarkerOptions
VisionRunningMode = mp.tasks.vision.RunningMode

try:
print("A Tentar ativar a Placa Gráfica (GPU) para ser mais rápido...") # Tenta configurar para usar a GPU

base_p, base_h = BaseOptions(model_asset_path=CAMINHO_MODELO_POSE, delegate=BaseOptions.Delegate.GPU), BaseOptions(model_asset_path=CAMINHO_MODELO_MAO, delegate=BaseOptions.Delegate.GPU)
detetor_pose =
PoseLandmarker.create_from_options(PoseLandmarkerOptions(base_options=base_p, running_mode=VisionRunningMode.VIDEO, num_poses=1))
detetor_mao =
HandLandmarker.create_from_options(HandLandmarkerOptions(base_options=base_h, running_mode=VisionRunningMode.VIDEO, num_hands=2))
print(">>> SUCESSO! GPU ATIVADA! <<<")
except Exception as e:
print(f"AVISO: GPU falhou ({e}). O Computador vai usar o Processador (CPU)...")
base_p, base_h = BaseOptions(model_asset_path=CAMINHO_MODELO_POSE, delegate=BaseOptions.Delegate.CPU), BaseOptions(model_asset_path=CAMINHO_MODELO_MAO, delegate=BaseOptions.Delegate.CPU)
detetor_pose =
PoseLandmarker.create_from_options(PoseLandmarkerOptions(base_options=base_p, running_mode=VisionRunningMode.VIDEO, num_poses=1))
detetor_mao =
HandLandmarker.create_from_options(HandLandmarkerOptions(base_options=base_h, running_mode=VisionRunningMode.VIDEO, num_hands=2))

# 2. Iniciar Câmara (Usa o nosso 'Leitor Rápido')

fluxo = FluxoCamera(src=INDICE_CAMERA, width=LARGURA_CAMERA, height=ALTURA_CAMERA).iniciar()
time.sleep(2.0) # Espera 2 segundos para a câmara "aquecer" (ajustar luz)

# Criar a janela onde vamos ver o vídeo

cv2.namedWindow("Detecao OTIMIZADA", cv2.WINDOW_NORMAL) cv2.resizeWindow("Detecao OTIMIZADA", 1280, 720)

print("\n" + "="*60)
print("A INICIAR - MODO SEM DELAY")
print("="*60 + "\n")

# --- MAPA DE CONEXÕES (Quais pontos ligam a quais) ---CONEXOES_POSE_BRACOS = [

(11, 13), (13, 15), (12, 14), (14, 16), # Braços (11, 12), (23, 24), (11, 23), (12, 24) # Tronco
]

# Mapa da mão (se o MediaPipe não tiver, usamos este manual)

CONEXOES_MAO = mp.solutions.hands.HAND_CONNECTIONS if hasattr(mp.solutions, 'hands') else [
(0, 1), (1, 2), (2, 3), (3, 4), (0, 5), (5, 6),
(6, 7), (7, 8), (0, 9), (9, 10), (10, 11), (11, 12),
(0, 13), (13, 14), (14, 15), (15, 16), (0, 17), (17, 18), (18, 19), (19, 20), (5, 9), (9, 13), (13, 17)
]

# --- LOOP PRINCIPAL (Onde a magia acontece) ---

# O programa fica preso aqui dentro a repetir isto infinitamente tempo_ant = time.time()

contagem_quadros = 0

while True:
# 1. Ler Nova Imagem

quadro = fluxo.ler()
if quadro is None: continue

# 2. Calcular FPS (Velocidade do programa) tempo_atual = time.time()

dt = tempo_atual - tempo_ant
if dt > 0:
fps = 1 / dt
else:
fps = 0
tempo_ant = tempo_atual
contagem_quadros += 1

# 3. Preparar Imagem para a IA (Converter cores)

rgb = cv2.cvtColor(quadro, cv2.COLOR_BGR2RGB)
imagem_mp = mp.Image(image_format=mp.ImageFormat.SRGB, data=rgb) timestamp_ms = int(time.time() * 1000)

# 4. EXECUTAR DETEÇÃO (Perguntar à IA onde está o corpo e a mão) resultado_pose = detetor_pose.detect_for_video(imagem_mp, timestamp_ms) resultado_mao = detetor_mao.detect_for_video(imagem_mp, timestamp_ms)

saida = quadro.copy() # Fazer uma cópia para desenhar por cima cv2.putText(saida, f"FPS: {int(fps)}", (saida.shape[1]-150, 50), cv2.FONT_HERSHEY_SIMPLEX, 1, (0, 255, 0), 2)

angulo_braco, orientacao_braco, estado_flexao = None, "Indefinido", "Estendido"

# 5. Se detetou CORPO:

if resultado_pose.pose_landmarks:
plm = resultado_pose.pose_landmarks[0] # Tenta descobrir o lado
lado = "Direita"
if resultado_mao.hand_landmarks:
lado =
determinar_lado_mao(*obter_centro_mao(resultado_mao.hand_landmarks[0]), plm) if resultado_mao.hand_landmarks else "Direita"

# Escolhe os pontos certos para Esquerda ou Direita

idx_s, idx_e, idx_w = (11, 13, 15) if lado == "Esquerda" else (12, 14, 16)
angulo_braco = calcular_angulo_3pts((plm[idx_s].x, plm[idx_s].y), (plm[idx_e].x, plm[idx_e].y), (plm[idx_w].x, plm[idx_w].y))

orientacao_braco = determinar_orientacao_braco(angulo_braco)
# Vê se o cotovelo está dobrado

estado_flexao, diff_y = determinar_flexao_braco(plm[idx_s].y, plm[idx_w].y)

# Escreve no ecrã e desenha (TRADUZIR OUTPUT VISUAL) cv2.putText(saida, f"Braco: {int(angulo_braco)} graus", (10, 30), cv2.FONT_HERSHEY_SIMPLEX, 0.6, (0, 255, 0), 2) cv2.putText(saida, f"Pos: {orientacao_braco}", (250, 30), cv2.FONT_HERSHEY_SIMPLEX, 0.6, (0, 255, 0), 2) cv2.putText(saida, f"Flex: {estado_flexao}", (10, 55), cv2.FONT_HERSHEY_SIMPLEX, 0.6, (0, 255, 255), 2) desenhar_marcos_personalizado(saida, plm, CONEXOES_POSE_BRACOS, COR_ARTICULACAO_POSE, COR_OSSO_POSE)

# 6. Se detetou MÃO:

if resultado_mao.hand_landmarks:
marcos_mao = resultado_mao.hand_landmarks[0]
# Calcula Rotação da palma

_, val_rotacao_mao, str_orientacao_mao, _ = calcular_rotacao_mao( marcos_mao, estado_flexao, orientacao_braco, lado)

# Verifica cada dedo

y0 = 80
for nome, ids in DEDOS.items():
esta_aberto = calcular_angulo_dedo(marcos_mao, ids) > LIMIARES_DEDOS[nome]
# TRADUZIR O NOME DOS DEDOS NO ECRÃ (3 LETRAS) nome_display = nome[:3].upper() # POL, IND, MED... status_display = "ABE" if esta_aberto else "FEC"

cv2.putText(saida, f"{nome_display}: {status_display}", (10, y0), cv2.FONT_HERSHEY_SIMPLEX, 0.5, (0, 255, 0) if esta_aberto else (0, 0, 255), 2) y0 += 20

# Desenha a barra de rotação

cv2.rectangle(saida, (10, y0+10), (160, y0+25), (100, 100, 100), 2) cv2.circle(saida, (10 + int((val_rotacao_mao + 1) / 2 * 150), y0+17), 6, (0, 255, 255), -1)
cv2.putText(saida, f"{str_orientacao_mao}", (10, y0+45), cv2.FONT_HERSHEY_SIMPLEX, 0.6, (0, 255, 255), 2)

desenhar_marcos_personalizado(saida, marcos_mao, CONEXOES_MAO, COR_ARTICULACAO_MAO, COR_OSSO_MAO)

# 7. Mostrar a imagem final

cv2.imshow("Detecao OTIMIZADA", saida)

# Se carregar no ESC (tecla 27), sai do programa if (cv2.waitKey(1) & 0xFF) == 27: break

# Limpeza final

fluxo.parar()
cv2.destroyAllWindows()

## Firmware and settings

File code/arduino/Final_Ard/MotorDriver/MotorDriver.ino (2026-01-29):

/*
 * ======================================================================================
 *                              FILE NAME: MotorDriver.ino
 * ======================================================================================
 *
 * BEGINNER DESCRIPTION:
 * This is a program for an Arduino Mega. The Arduino is like the electronic "brain"
 * that controls the robotic arm.
 *
 * What this program does:
 * 1. Receives orders from the "vision brain" (the Raspberry Pi or computer).
 * 2. Orders come in the form of a text message (ex: "$1,0,1,1,1,1,1,90").
 * 3. The Arduino reads this message and translates it into physical movements in the motors.
 *
 * TYPES OF MOTORES USED:
 * - Servo Motors (controlled by PCA9685 board): Used for fingers, elbow and hand rotation.
 * - Stepper Motor (controlled by another Arduino Uno): Used to rotate the base of the arm.
 *
 * LANGUAGE: C++ (Standard Arduino language)
 * ======================================================================================
 */

// --- LIBRARIES (Code Collections) ---
// These lines "call" extra code already written by others
// to help us talk to specific components.
#include <Wire.h>                     // Allows I2C communication (used to talk to servo board)
#include <Adafruit_PWMServoDriver.h>  // Specific library to control servo board (PCA9685)

// Create the "object" that controls the servos. Imagine this as hiring a manager for motors.
Adafruit_PWMServoDriver pwm = Adafruit_PWMServoDriver();

// --- CALIBRATION (Mechanical Adjustments) ---
// These values define physical limits of motors so they don't break the arm.
// A servo motor moves based on a "pulse" signal.
#define PULSE_MIN  100  // Pulse value for motor to go to MINIMUM position
#define PULSE_MAX  500  // Pulse value for motor to go to MAXIMUM position

// --- GLOBAL VARIABLES ---
// Drawers in memory to store numbers we will use often.
int PULSE_OPEN;   // Will store the value needed to OPEN the hand (90 degrees)
int PULSE_CLOSED; // Will store the value needed to CLOSE the hand (0 degrees)

// --- PIN DEFINITION (Where we plug cables) ---
// PCA9685 board has ports numbered 0 to 15.
// Here we give names to those numbers to make code easier to read.
#define PIN_ELBOW   0   // Elbow motor connected to port 0
#define PIN_THUMB   13  // Thumb
#define PIN_INDEX   11  // Index Finger
#define PIN_MIDDLE  10  // Middle Finger
#define PIN_RING    15  // Ring Finger
#define PIN_PINKY   14  // Pinky Finger
#define PIN_ROTATION 12 // Motor that rotates the wrist

// --- COMMUNICATION (Computer Talk) ---
// Variables to receive text from Raspberry Pi
char g_pcBuffer[100];          // A "sentence" can have up to 100 letters
bool g_messageReady = false;   // "Flag" that goes up when a complete sentence arrived
int g_bufferIndex = 0;         // Counter to know which letter we are at

/*
 * ======================================================================================
 * SETUP FUNCTION (Initial Configuration)
 * This function runs only ONCE when we turn on the Arduino.
 * Used to prepare everything before starting work.
 * ======================================================================================
 */
void setup() {
  // 1. Start Communications (Radio Channels)
  // Serial:  Connection to computer (USB cable) to see error messages on screen (Debug).
  // Serial2: Connection to Raspberry Pi (the vision brain).
  // Serial3: Connection to Arduino Uno (which controls rotating base).
  
  Serial.begin(115200);   // Fast speed for PC
  Serial2.begin(115200);  // Fast speed for Raspberry Pi
  Serial3.begin(9600);    // Normal speed for Arduino Uno

  // 2. Start Servo Controller (PCA9685)
  pwm.begin();           // Wakes up servo board
  pwm.setPWMFreq(50);    // Sets frequency to 50Hz (standard for analog servos)
  Wire.setClock(400000); // Speeds up I2C communication to respond faster

  // 3. POSITION PRE-CALCULATION
  // The 'map' function translates degrees (0-180) to motor pulse values (100-500).
  // We calculate this now so we don't have to do math all the time.
  PULSE_OPEN   = map(0, 0, 180, PULSE_MIN, PULSE_MAX);   // 0 degrees = Open
  PULSE_CLOSED = map(180, 0, 180, PULSE_MIN, PULSE_MAX); // 180 degrees = Closed

  delay(10); // Small pause to ensure everything stabilizes

  // 4. Start Position
  moveAll(0); // Sends all servos to position 0 (rest)
  
  // Messages for human to read on PC screen
  Serial.println("MEGA READY (TURBO MODE 115200) + ROTATION + DEBUG ACTIVATED");
  Serial.println("Example debug messages: ");
  Serial.println("$1,0,1,1,1,1,1,90");
  Serial.println("Waiting for commands...");
}

/*
 * ======================================================================================
 * LOOP FUNCTION (Infinite Cycle)
 * This function repeats forever, thousands of times per second.
 * This is where the Arduino "lives" and works.
 * ======================================================================================
 */
void loop() {
  // --- PART 1: LISTEN TO RASPBERRY PI ---
  // While there is data coming from Pi and message is not finished...
  while (Serial2.available() > 0 && !g_messageReady) {
    char inChar = Serial2.read(); // Reads one letter
    
    if (inChar == '$') {
      // The symbol '$' marks the START of a new message.
      // If we see this, restart counter to write from zero.
      g_bufferIndex = 0;
    } 
    else if (inChar == '\n') {
      // The symbol '\n' (new line) marks the END of message.
      g_pcBuffer[g_bufferIndex] = '\0'; // Closes the "string" (text) correctly
      g_messageReady = true;            // Raises flag: "We have an order!"
    } 
    else if (g_bufferIndex < 99) {
      // If not start or end, it is content (ex: '1', ',', '9').
      // Save in buffer and advance counter.
      g_pcBuffer[g_bufferIndex] = inChar;
      g_bufferIndex++;
    }
  }

  // --- PART 2: EXECUTE ORDER ---
  // If flag is raised (complete message received)...
  if (g_messageReady) {
    processMessageFast(); // Calls function that distributes tasks
    g_messageReady = false;  // Lowers flag and prepares for next
    g_bufferIndex = 0;
  }
}
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

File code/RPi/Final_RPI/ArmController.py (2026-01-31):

"""
======================================================================================
                            FILE NAME: ArmController.py
======================================================================================

BEGINNER DESCRIPTION:
This program runs on a Raspberry Pi 5 (a small computer).
It uses a camera to see the movement of a person's arm and hand and
translates these movements into commands that the robot can understand.

What this program does:
1. Captures video from the camera (Raspberry Pi Camera Module 3).
2. Uses "Artificial Intelligence" (MediaPipe) to detect where the fingers, elbow, and shoulder are.
3. Performs mathematical calculations to determine if the arm is extended or bent, and where it is pointing.
4. Sends this information via serial comunication (RX/TX) to the Arduino, which controls the motors.

LANGUAGE: Python
======================================================================================
"""

# --- IMPORT LIBRARIES (Pre-made tools) ---
import cv2                  # "OpenCV": Tool to process images and video
import mediapipe as mp      # "MediaPipe": Google's tool that detects hands and bodies
import math                 # Math tools (angles, distances)
import statistics           # To calculate averages
import time                 # To control time (pauses, measure delays)
import serial               # To talk to the Arduino via USB/Serial cable
from picamera2 import Picamera2 # Specific library to control the Raspberry Pi 5 camera (Pi Camera Module 3)
import numpy as np          # Tool for advanced mathematical calculations

# ------------------ OPTIMIZED CONFIGURATION FOR RASPBERRY PI ------------------
# We define the image size. Smaller images are processed faster.
FRAME_WIDTH = 640   # Width in pixels
FRAME_HEIGHT = 480  # Height in pixels
FPS_TARGET = 30     # We aim for 30 images per second (normal video smoothness)

# --- COMMUNICATION CONFIGURATION (SERIAL) ---
# Here we say where the Arduino is connected and how fast to talk to it.
SERIAL_PORT = "/dev/ttyAMA0"  # Internal Raspberry Pi port (GPIO Pins)
BAUD_RATE = 115200            # Speed of conversation (bits per second). Must be the same on Arduino!
SEND_INTERVAL = 0.1           # We only send data every 0.1 seconds (10 times/second) to avoid clogging

# ---------- ADJUSTABLE PARAMETERS (Tuning) ----------
# Thresholds: Reference values. If we pass this value, it is considered "Open" or "Closed".

# Fingers: Minimum angle to consider the finger OPEN.
TH_THUMB = 150.0
TH_INDEX = 160.0
TH_MIDDLE = 150.0
TH_RING = 150.0
TH_PINKY = 140.0

# Arm: Angles to know where the arm is pointing.
TH_ARM_LEFT = 70          # 0 to 70 degrees: Arm facing the body (Left)
TH_ARM_CENTER_MAX = 130   # 70 to 130 degrees: Arm in front
                          # 130 to 180 degrees: Arm outwards (Right)

# Flexion: Vertical height difference (Y) between wrist and shoulder to know if arm is raised.
TH_FLEXION_Y = 0.1  # If difference is greater than 0.1, we consider it "Flexed" (Bent)
# ---------------------------------------------------------------

# --- INITIALIZE MEDIAPIPE (The Artificial Intelligence) ---
mp_pose = mp.solutions.pose       # Module to detect body (shoulders, elbows)
mp_hands = mp.solutions.hands     # Module to detect hands/fingers
mp_drawing = mp.solutions.drawing_utils # Useful for drawing the "skeletons" on the screen

# Visual configuration of the lines we will draw on the screen
drawing_spec_thin = mp_drawing.DrawingSpec(thickness=1, circle_radius=1)
drawing_spec_conn = mp_drawing.DrawingSpec(thickness=1)

# Finger Definition: Dictionary that says which points (landmarks) form each finger
FINGERS = {
    "thumb": [1, 2, 4],     # Specific points of the hand that form the thumb, usually 2, 3, 4
    "index": [5, 6, 8],
    "middle": [9, 10, 12],
    "ring": [13, 14, 16],
    "pinky": [17, 18, 20]
}

# Associating thresholds to each finger
FINGER_THRESHOLDS = {
    "thumb": TH_THUMB,
    "index": TH_INDEX,
    "middle": TH_MIDDLE,
    "ring": TH_RING,
    "pinky": TH_PINKY
}

# -------- START CONNECTION TO ARDUINO --------
try:
    arduino = serial.Serial(SERIAL_PORT, BAUD_RATE, timeout=1)
    time.sleep(2) # Wait 2 seconds for Arduino to wake up properly
    print(f"Connected to Arduino on {SERIAL_PORT}")
except Exception as e:
    # If it fails (cable disconnected?), notify but do not stop the program
    print(f"Could not connect to Arduino: {e}")
    print(f"   Check the port. You can use: ls /dev/tty*")
    arduino = None

# -------- LOGIC FUNCTIONS (The Brain of the Program) --------

def calculate_angle_3pts(a, b, c):
    """
    Calculates the angle between 3 points (like an elbow: shoulder, elbow, wrist).
    Inputs: Points a, b, c (x,y coordinates).
    Returns: Angle in degrees.
    """
    # Vector math (calculation of differences and dot products)
    ax, ay = a[0]-b[0], a[1]-b[1]
    cx, cy = c[0]-b[0], c[1]-b[1]
    num = ax*cx + ay*cy
    den = math.hypot(ax, ay) * math.hypot(cx, cy) + 1e-8
    cosv = max(-1.0, min(1.0, num/den))
    ang = math.degrees(math.acos(cosv))
    return ang

def calculate_finger_angle(hand_landmarks, ids):
    """
    Measures the angle at the middle 'hinge' of the finger.
    """
    a = hand_landmarks.landmark[ids[0]]
    b = hand_landmarks.landmark[ids[1]]
    c = hand_landmarks.landmark[ids[2]]
    return calculate_angle_3pts((a.x,a.y),(b.x,b.y),(c.x,c.y))

def get_hand_center(hand_landmarks):
    """Calculates the center point of the hand (average of all points)."""
    xs = [lm.x for lm in hand_landmarks.landmark]
    ys = [lm.y for lm in hand_landmarks.landmark]
    return (statistics.mean(xs), statistics.mean(ys))

def determine_hand_side(hand_cx, hand_cy, pose_landmarks):
    """
    Figures out if the hand we are seeing is the RIGHT or LEFT one.
    Checks which wrist (shoulder/body landmarks) is closer.
    """
    if pose_landmarks is None:
        return None
    lw = pose_landmarks.landmark[15] # Body's left wrist
    rw = pose_landmarks.landmark[16] # Body's right wrist
    
    # Calculate distance (Pythagorean Theorem)
    dl = math.hypot(hand_cx - lw.x, hand_cy - lw.y)
    dr = math.hypot(hand_cx - rw.x, hand_cy - rw.y)
    
    return "Left" if dl < dr else "Right"

def determine_arm_orientation(angle):
    """Tells where the arm is pointing based on the shoulder angle."""
    if angle <= TH_ARM_LEFT:
        return "Left (Body)" 
    elif angle <= TH_ARM_CENTER_MAX:
        return "Center (Front)" 
    else:
        return "Right (Out)"

def determine_arm_flexion(shoulder_y, wrist_y):
    """
    Tells if the arm is raised (flexed).
    Compares the height (Y) of the shoulder and the wrist.
    """
    diff_y = abs(shoulder_y - wrist_y)
    if diff_y > TH_FLEXION_Y:
        return "Flexed", diff_y
    else:
        return "Extended", diff_y
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

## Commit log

2025-11-12 Add Arduino CNC and Mega control sketches
    Added arduinoCNCfinal.ino for CNC shield stepper control via SoftwareSerial, and ArduinoMegaTest.ino for Mega-based servo and stepper coordination with serial communication between Raspberry Pi, Mega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
2025-11-18 Add MediaPipe hand and pose tracking script
    This script initializes a camera and processes hand and pose landmarks using MediaPipe, sending data to an Arduino via serial communication.
2025-11-19 Add Arduino sketch for MG996R servo control via PCA9685
    Introduces a new Arduino sketch that demonstrates controlling an MG996R servo motor using the Adafruit PCA9685 PWM driver. The code includes functions to move the servo to 0, 90, and 180 degrees, wit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
2025-11-27 Add servo and I2C test sketches; optimize Mega code
    Added new Arduino sketches for I2C device scanning, single servo test on UNO, and slow servo sweep on MEGA. Refactored ArduinoMegaTest.ino to use PCA9685 for servo control, optimized serial communica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
2025-11-28 Add visionALGT.py and update Arduino CNC logic
    Added a new Python script for hand and arm gesture recognition using MediaPipe and Picamera2 on Raspberry Pi, enabling serial communication with Arduino. Refactored arduinoCNCfinal.ino to simplify st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
2025-12-04 Add Arduino servo and current measurement scripts
    Added megaNotPCA.ino for controlling servos via Arduino Mega and getCurrent.ino for measuring voltage and current using the INA219 sensor. These scripts support hardware control and monitoring for ro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
2025-12-04 Update servo calibration and serial communication
    Adjusted servo open angle to 180 degrees and updated pulse width calibration to correct offset and prevent ticking. Changed serial communication: Raspberry Pi now uses Serial2 at 115200 baud, Uno uses Serial3 at 9600 baud, and message processing now reads from Serial2 instead of Serial. Servos are now attached with custom pulse width limits.
    [megaNotPCA.ino]
2025-12-19 Add serial monitor test and adjust servo calibration
    Added Mega_serial_monitor_test.ino for debugging and command testing via serial monitor. Updated ArduinoMegaTest.ino to adjust servo calibration values (SERVOMIN and SERVOMAX) for improved servo rang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
2026-01-08 Add hand and arm tracking with serial control integration
    Added mediapipe_teste_serial2.py for hand and arm pose detection on Raspberry Pi with serial output to Arduino, visionALGT2.py for visual debugging and hand/arm tracking, and ArduinoMegaTest2.ino for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
2026-01-17 Update finger mapping and add debug to Arduino code
    Adjusted the thumb mapping and hand rotation normalization in mediapipe_teste_serial2.py for improved accuracy. Updated ArduinoMegaTest2.ino with new PCA port assignments, increased serial speed for 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
2026-01-23 Traduzir script de visão de espanhol para português
    O script visionALGT2.py foi totalmente traduzido do espanhol para o português, incluindo variáveis, comentários, strings de interface e mensagens de console. Os nomes das variáveis e funções foram ad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
2026-01-23 Add beginner-friendly comments and refactor code
    Expanded and clarified comments in mediapipe_teste_serial2.py, visionALGT2.py, and ArduinoMegaTest2.ino to make the code more accessible for beginners. Improved structure, added detailed explanations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
2026-01-29 Add PC vision script and models; remove RPi script
    Add a PC-optimized vision implementation and model assets: code/PC/visionALGT2.py (MediaPipe Tasks, GPU fallback, camera thread) plus hand_landmarker.task, pose_landmarker_lite.task and pose_landmark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
2026-01-31 Add PT PC debugger; reorganize and refactor code
    Large repo reorganization and vision/rotation logic refactor:
    - Add README.md with project overview, structure and usage (Portuguese).
    - Update REQUIREMENTS.txt to clarify MediaPipe and other deps for RPi.
    - Refactor code/PC/VisionDebugger_PC.py: add THICKNESS constant, extract arm orientation/flexion helpers, expand and normalize calculate_hand_rotation (adds side handling, improved axis logic and tex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
    - Add full Portuguese PC debugger: code/PC/VisionDebugger_PC_PT.py (new, translated and feature-complete implementation using MediaPipe Tasks API).
    - Update Raspberry Pi controller files: ren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
2026-01-31 Docs: update comments and rename Arduino file
    Minor documentation and rename changes across PC, RPi and Arduino code:
    - code/PC/VisionDebugger_PC_PT.py: added comment suggesting 'pose_landmarker_heavy.task' for better performance and cleaned up whitespace in the header.
    - code/RPi/Final_RPI/ArmController.py: clarified camera source (Raspberry Pi Camera Module 3) and clarified serial communication wording.
    - code/RPi/Final_RPI/ArmController_PT.py: same clarifications in Portuguese (camera module and serial RX/TX wording), plus header filename update.
    - code/arduino/Final_Ard/MotorDriver_PT/: renamed MotorDDriver_PT.ino -> MotorDriver_PT.ino and updated the file header to match the new filena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
2026-02-01 Separate line/point thickness and set camera index
    Change default camera index from 2 to 1 and introduce distinct thickness constants for drawings. Renamed ESPESSURA to ESPESSURA_LINHAS and added ESPESSURA_PONTOS, updating the drawing routine to use 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
2026-02-02 Add CNC Arduino sketch and fix UART routing
    Add Arduino_Uno_CNC_Final.ino: a new sketch for an A4988-driven stepper (CNC shield X axis) implementing a simple state machine to move to centre/left/right via serial commands ('0','1','2'), with configurable step counts and moveMotor pulse routine. Update MotorDriver_PT.ino: swap Serial2/Serial3 roles and baud rates so the Arduino Uno is on Serial2 (9600) and the Raspberry Pi is on Serial3 (115200); adjust the corresponding Serial.read/write calls and comments to match the corrected wiring.
    [Arduino_Uno_CNC_Final.ino, MotorDriver_PT.ino]
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2026-05-11 Add custom base STLs and media assets
    Add STL files for the custom base (Custom_Base_STL/) and include multiple new media assets (images and MP4s) for the project. Remove placeholder .txt media descriptors and replace GIF demo assets with MP4s; update README to reference the new media files, add a link to the Custom_Base_STL folder, and note that the base parts are custom-made (not from InMoov).
    [Alongamento.STL, Base_Braco_ASS_2.STL, Base_Braco_SUP_ASS_2.STL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]
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
